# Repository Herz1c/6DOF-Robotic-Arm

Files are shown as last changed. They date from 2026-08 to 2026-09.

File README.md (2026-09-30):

# A robot arm you can print

I am building a six-axis robot arm that you can make at home. Almost every part
of it comes off a 3D printer. What is left over is bearings, stepper
motors and screws, all of it for less than 400$. Alongside the arm I am also
building an AI model for object detection which will run on a Rockchip RK3588.
Camera mount was already added to the model and assembly guides.

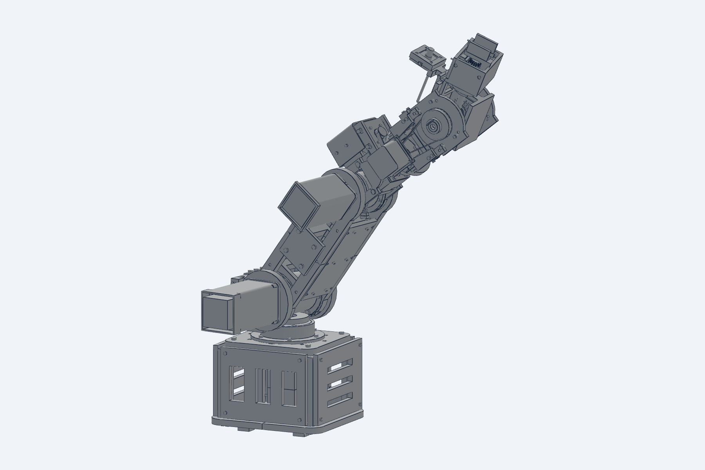
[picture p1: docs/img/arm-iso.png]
The arm


## Where this is right now

Work in progress. What sits in this repository today is the printable parts and
the assembly guide, nothing else.

The arm is fully designed, and I have checked the motion and the fits in CAD.
But I have not built it, and neither has anyone else. So treat these files as
something to print and look at, not as a finished kit that is known to work.

## The assembly guide

The assembly guide has been finally published, both czech and english versions.
The manuals were created not only to show how to put the printed pieces together,
but also to act as a shopping list for all the necessary parts. Soon I am planning 
on publishing links for the items needed (as soon as I finish the build and assure good
quality of the parts)

There is also a 3D version of the guide that runs in the browser:
[herz1c.github.io/6DOF-Robotic-Arm](https://herz1c.github.io/6DOF-Robotic-Arm/).
It puts the arm together one part at a time, all 263 steps, and you can turn the
model around to see where each part goes and which side the screws come from.
It works on a phone and there is nothing to install.

## What is in here

Everything printable, in `print_parts`, split into seven folders that follow the
order you need them:

- base and J1 turret
- J2 shoulder
- J3 elbow and upper arm
- J4 forearm roll
- J5 and J6 differential wrist
- gripper
- forearm lids

Both manuals are in `docs` folder, the browser guide in `docs/guide`

Every part has an STL to print and a STEP next to it if you would rather remesh
it or change something. Each folder has a short readme with the material, layer
height, perimeters, infill, supports and print orientation for each part.

## How the arm works

Six axes, plus a two-finger gripper on the end.

The wrist is the part I am most pleased with. Both wrist motors sit back on the
forearm and never turn with the joint. Two belts drive two input spools, and the
wrist reads the sum of them as pitch and the difference as roll. That means the
tool can spin without ever stopping, because nothing winds up, and it keeps the
weight of two motors off the far end of the arm where you feel it most.

Homing runs on a single pair of wires. The switches are wired in series, so one
break tells the controller a flag arrived, and the axis you were moving tells it
which. The wrist pitch has no switch at all. It finds home by driving gently into
a printed stop.

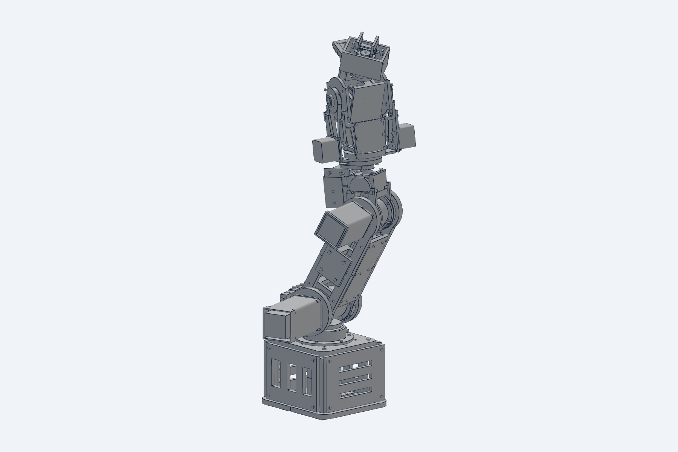
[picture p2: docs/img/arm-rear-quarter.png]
The arm from behind


## A word about material

The readmes name a material for every part and it is worth following. Parts in
the load path or next to a motor are ASA, because stepper bodies get hot enough
that PLA slowly gives way under the permanent squeeze that every bolted joint
lives under.

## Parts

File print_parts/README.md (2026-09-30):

# Printable parts

Every part of the arm that comes off a printer, split into the order you need it. Start with folder 01 and work down - you can begin assembling the base while the rest is still printing.

- `01_base_and_j1` - Base and J1 turret, 27 parts
- `02_j2_shoulder` - J2 shoulder, 9 parts
- `03_j3_elbow` - J3 elbow and upper arm, 19 parts
- `04_j4_forearm` - J4 forearm roll, 26 parts
- `05_j5_j6_wrist` - J5 and J6 differential wrist, 28 parts
- `06_gripper` - Gripper, 9 parts
- `07_forearm_lids` - Forearm lids, 2 parts

Each folder has an STL and a STEP for every part. Print the STL; the STEP is there if you would rather re-mesh it yourself or change something.

The complete Czech and English assembly guides are published in `docs/manual`. Folder order and the three-digit file numbers follow the same build order.

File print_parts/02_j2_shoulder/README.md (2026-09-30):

# J2 shoulder

The shoulder joint and the parts that hold its bearings.

Print these in the order the files are numbered. Settings below are what the part is designed for, not a suggestion - the material choice in particular matters, see the note at the bottom.

1. **HomeSwitchBracket J2** - PETG, 0.15 mm layers, 4 perimeters, 30% infill, supports on overhangs only. Orientation: largest face on the bed, X axis vertical.
2. **J2 FlangedBearingHub** - ASA, 0.20 mm layers, 5 perimeters, 60% infill, no supports. Orientation: bearing bore vertical so it stays round without supports.
3. **HomeFlag J2** - PETG, 0.20 mm layers, 3 perimeters, 30% infill, no supports. Orientation: largest face on the bed, Y axis vertical.
4. **J2 6807 Left OuterRaceSpacer 9mm** - PETG, 0.20 mm layers, 4 perimeters, 30% infill, no supports. Orientation: largest face on the bed, Y axis vertical.
5. **J2 6807 Right OuterRaceSpacer 9mm** - PETG, 0.20 mm layers, 4 perimeters, 30% infill, no supports. Orientation: largest face on the bed, Y axis vertical.
6. **J2 SteppedBearingRetainerAdapter** - ASA, 0.20 mm layers, 5 perimeters, 30% infill, no supports. Orientation: bearing bore vertical so it stays round without supports.
7. **J2 6807 Right ExternalRetainer** - ASA, 0.20 mm layers, 5 perimeters, 30% infill, no supports. Orientation: bearing bore vertical so it stays round without supports.
8. **J2 ActuatorServiceCover M3x4** - PETG, 0.20 mm layers, 4 perimeters, 30% infill, no supports. Orientation: largest face on the bed, X axis vertical.
9. **P217 J2HubDrillJig** - ASA, 0.20 mm layers, 4 perimeters, 60% infill, no supports. Orientation: largest face on the bed, Y axis vertical. This one is a tool, not a part of the arm: the bought J2 hub has no bolt circle, and its eight M5 holes are drilled through this jig.

ASA parts sit in the load path or next to a motor. Stepper bodies run hot enough that PLA creeps there under the permanent load every bolted joint carries, so those parts are not a place to save money. PETG parts are covers, gears, pulleys and brackets.

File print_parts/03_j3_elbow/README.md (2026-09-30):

# J3 elbow and upper arm

The upper arm shell and the elbow joint.

Print these in the order the files are numbered. Settings below are what the part is designed for, not a suggestion - the material choice in particular matters, see the note at the bottom.

1. **UpperArmCheek Left A J2SixBoltHoles** - ASA, 0.20 mm layers, 5 perimeters, 30% infill, supports on overhangs only. Orientation: largest face on the bed, Y axis vertical.
2. **UpperArmCheek Left B 6807InnerShoulder** - ASA, 0.20 mm layers, 5 perimeters, 30% infill, supports on overhangs only. Orientation: largest face on the bed, Y axis vertical.
3. **UpperArmSplice Left** - ASA, 0.20 mm layers, 5 perimeters, 30% infill, no supports. Orientation: largest face on the bed, Y axis vertical.
4. **UpperArmRib A** - ASA, 0.20 mm layers, 5 perimeters, 30% infill, no supports. Orientation: upright, 5 mm brim.
5. **UpperArmRib B** - ASA, 0.20 mm layers, 5 perimeters, 30% infill, no supports. Orientation: upright, 5 mm brim.
6. **UpperArmRibC ElbowSweepWindow** - ASA, 0.20 mm layers, 5 perimeters, 30% infill, no supports. Orientation: upright, 5 mm brim.
7. **UpperArmBottomCover** - PETG, 0.20 mm layers, 4 perimeters, 30% infill, no supports. Orientation: largest face on the bed, Z axis vertical.
8. **HomeSwitchBracket J3** - PETG, 0.15 mm layers, 4 perimeters, 30% infill, supports on overhangs only. Orientation: largest face on the bed, Y axis vertical.
9. **J3 Dual6807JournalHub** - ASA, 0.20 mm layers, 5 perimeters, 60% infill, no supports. Orientation: bearing bore vertical so it stays round without supports.
10. **HomeFlag J3** - PETG, 0.20 mm layers, 3 perimeters, 30% infill, no supports. Orientation: largest face on the bed, Y axis vertical.
11. **ElbowCheek Left** - ASA, 0.20 mm layers, 5 perimeters, 30% infill, supports on overhangs only. Orientation: largest face on the bed, Y axis vertical.
12. **ElbowCheek Right** - ASA, 0.20 mm layers, 5 perimeters, 30% infill, supports on overhangs only. Orientation: largest face on the bed, Y axis vertical.
13. *Not used - there is no file 013. The printed left inner race collar was dropped; the gearbox's own machined register stops the bearing instead.*
14. **P216 J3 LoadCartridge 68mmGearbox** - ASA, 0.15 mm layers, 4 perimeters, 60% infill, supports on overhangs only. Orientation: largest face on the bed, X axis vertical.
15. **UpperArmCheek Right A J2SixBoltHoles** - ASA, 0.20 mm layers, 5 perimeters, 30% infill, supports on overhangs only. Orientation: largest face on the bed, Y axis vertical.
16. **UpperArmCheek Right B 6807InnerShoulder M3Pilots** - ASA, 0.20 mm layers, 5 perimeters, 30% infill, supports on overhangs only. Orientation: largest face on the bed, Y axis vertical.
17. **UpperArmSplice Right** - ASA, 0.20 mm layers, 5 perimeters, 30% infill, no supports. Orientation: largest face on the bed, Y axis vertical.
18. **J3 InnerRaceSetScrewCollar Right** - PETG, 0.20 mm layers, 4 perimeters, 30% infill, no supports. Orientation: bearing bore vertical so it stays round without supports.
19. **J3 Right6807 OuterRaceRetainer Access** - ASA, 0.20 mm layers, 4 perimeters, 30% infill, no supports. Orientation: bearing bore vertical so it stays round without supports.
20. **UpperArmTopCover ElbowSweepWindow** - PETG, 0.20 mm layers, 4 perimeters, 30% infill, no supports. Orientation: largest face on the bed, Z axis vertical.

ASA parts sit in the load path or next to a motor. Stepper bodies run hot enough that PLA creeps there under the permanent load every bolted joint carries, so those parts are not a place to save money. PETG parts are covers, gears, pulleys and brackets.

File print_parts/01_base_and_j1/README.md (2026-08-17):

# Base and J1 turret

The frame that stands on the table and carries everything else, plus the first axis.

Print these in the order the files are numbered. Settings below are what the part is designed for, not a suggestion - the material choice in particular matters, see the note at the bottom.

1. **BaseFloor Left Anchored** - ASA, 0.20 mm layers, 5 perimeters, 30% infill, no supports. Orientation: largest face on the bed, Z axis vertical.
2. **BaseFloor Right Anchored** - ASA, 0.20 mm layers, 5 perimeters, 30% infill, no supports. Orientation: largest face on the bed, Z axis vertical.
3. **BaseFloor UpperSplicePlate** - ASA, 0.20 mm layers, 4 perimeters, 30% infill, no supports. Orientation: largest face on the bed, Z axis vertical.
4. **BaseFloor UpperSplicePlate (1)** - ASA, 0.20 mm layers, 4 perimeters, 30% infill, no supports. Orientation: largest face on the bed, Z axis vertical.
5. **BaseFoot MM** - ASA, 0.20 mm layers, 3 perimeters, 30% infill, no supports. Orientation: largest face on the bed, Z axis vertical.
6. **BaseFoot MP** - ASA, 0.20 mm layers, 3 perimeters, 30% infill, no supports. Orientation: largest face on the bed, Z axis vertical.
7. **BaseFoot PM** - ASA, 0.20 mm layers, 3 perimeters, 30% infill, no supports. Orientation: largest face on the bed, Z axis vertical.
8. **BaseFoot PP** - ASA, 0.20 mm layers, 3 perimeters, 30% infill, no supports. Orientation: largest face on the bed, Z axis vertical.
9. **BaseCornerPost FL** - ASA, 0.20 mm layers, 5 perimeters, 30% infill, no supports. Orientation: upright, 5 mm brim.
10. **BaseCornerPost FR** - ASA, 0.20 mm layers, 5 perimeters, 30% infill, no supports. Orientation: upright, 5 mm brim.
11. **BaseCornerPost RL** - ASA, 0.20 mm layers, 5 perimeters, 30% infill, no supports. Orientation: upright, 5 mm brim.
12. **BaseCornerPost RR** - ASA, 0.20 mm layers, 5 perimeters, 30% infill, no supports. Orientation: upright, 5 mm brim.
13. **BaseFrontPanel** - ASA, 0.20 mm layers, 5 perimeters, 30% infill, no supports. Orientation: largest face on the bed, Y axis vertical.
14. **BaseRearPanel** - ASA, 0.20 mm layers, 5 perimeters, 30% infill, no supports. Orientation: largest face on the bed, Y axis vertical.
15. **BaseLeftPanel** - ASA, 0.20 mm layers, 5 perimeters, 30% infill, no supports. Orientation: largest face on the bed, X axis vertical.
16. **BaseRightPanel** - ASA, 0.20 mm layers, 5 perimeters, 30% infill, no supports. Orientation: largest face on the bed, X axis vertical.
17. **J1 ReducerAndBearingAdapter** - ASA, 0.20 mm layers, 5 perimeters, 30% infill, no supports. Orientation: largest face on the bed, Z axis vertical.
18. **BaseTopPlate J1StackOpening** - ASA, 0.20 mm layers, 5 perimeters, 30% infill, no supports. Orientation: largest face on the bed, Z axis vertical.
19. **J1 DualBearingHousing Flanged** - ASA, 0.20 mm layers, 5 perimeters, 60% infill, supports on overhangs only. Orientation: bearing bore vertical so it stays round without supports.
20. **J1 6807 TopRetainer CSK** - ASA, 0.20 mm layers, 5 perimeters, 30% infill, no supports. Orientation: bearing bore vertical so it stays round without supports.
21. **HomeSwitchBracket J1** - PETG, 0.15 mm layers, 4 perimeters, 30% infill, supports on overhangs only. Orientation: largest face on the bed, Z axis vertical.
22. **P101A J1 JournalCartridge** - ASA, 0.20 mm layers, 5 perimeters, 60% infill, supports on overhangs only. Orientation: largest face on the bed, Z axis vertical.
23. **P101B LowerDeck** - ASA, 0.20 mm layers, 5 perimeters, 30% infill, no supports. Orientation: largest face on the bed, Z axis vertical.
24. **P101E RearBridge** - ASA, 0.20 mm layers, 5 perimeters, 30% infill, no supports. Orientation: largest face on the bed, X axis vertical.
25. **P101C J2Cheek Left** - ASA, 0.20 mm layers, 5 perimeters, 30% infill, supports on overhangs only. Orientation: largest face on the bed, Y axis vertical.
26. **P101D J2Cheek Right** - ASA, 0.20 mm layers, 5 perimeters, 30% infill, supports on overhangs only. Orientation: largest face on the bed, Y axis vertical.
27. **HomeFlag J1** - PETG, 0.20 mm layers, 3 perimeters, 30% infill, no supports. Orientation: largest face on the bed, Z axis vertical.

ASA parts sit in the load path or next to a motor. Stepper bodies run hot enough that PLA creeps there under the permanent load every bolted joint carries, so those parts are not a place to save money. PETG parts are covers, gears, pulleys and brackets.

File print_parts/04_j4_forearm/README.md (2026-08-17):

# J4 forearm roll

Forearm rotation, its belt drive and bearing cartridge.

Print these in the order the files are numbered. Settings below are what the part is designed for, not a suggestion - the material choice in particular matters, see the note at the bottom.

1. **P304A J4 BearingCartridge** - ASA, 0.20 mm layers, 5 perimeters, 60% infill, supports on overhangs only. Orientation: largest face on the bed, X axis vertical.
2. **P304B BottomFoot Rear** - ASA, 0.20 mm layers, 4 perimeters, 30% infill, no supports. Orientation: largest face on the bed, Z axis vertical.
3. **P304C BottomFoot Front** - ASA, 0.20 mm layers, 4 perimeters, 30% infill, no supports. Orientation: largest face on the bed, X axis vertical.
4. **P304D PG19Carrier Rear PosY** - ASA, 0.20 mm layers, 4 perimeters, 30% infill, supports on overhangs only. Orientation: largest face on the bed, Y axis vertical.
5. **P304E PG19Carrier Rear NegY** - ASA, 0.20 mm layers, 4 perimeters, 30% infill, supports on overhangs only. Orientation: largest face on the bed, Y axis vertical.
6. **P304F PG19Carrier Front PosY** - ASA, 0.20 mm layers, 5 perimeters, 30% infill, supports on overhangs only. Orientation: largest face on the bed, X axis vertical.
7. **P304G PG19Carrier Front NegY** - ASA, 0.20 mm layers, 5 perimeters, 30% infill, supports on overhangs only. Orientation: largest face on the bed, X axis vertical.
8. **HomeSwitchBracket J4** - PETG, 0.15 mm layers, 4 perimeters, 30% infill, supports on overhangs only. Orientation: largest face on the bed, X axis vertical.
9. **J4 BearingRetainer Rear FlushCSK** - ASA, 0.20 mm layers, 4 perimeters, 30% infill, no supports. Orientation: bearing bore vertical so it stays round without supports.
10. **J4 BearingRetainer Front** - ASA, 0.20 mm layers, 4 perimeters, 30% infill, no supports. Orientation: bearing bore vertical so it stays round without supports.
11. **36T HTD3M DFlat OutputFlange SingleM5Clamp** - ASA, 0.20 mm layers, 5 perimeters, 60% infill, no supports. Orientation: largest face on the bed, X axis vertical.
12. **P401A J4 OutputFlangeWithTabs** - ASA, 0.20 mm layers, 5 perimeters, 60% infill, no supports. Orientation: largest face on the bed, X axis vertical.
13. **P401B ForearmSideFrame PosY** - ASA, 0.20 mm layers, 5 perimeters, 30% infill, no supports. Orientation: largest face on the bed, Y axis vertical.
14. **P401D RearCrossbar Upper** - ASA, 0.20 mm layers, 4 perimeters, 30% infill, no supports. Orientation: largest face on the bed, X axis vertical.
15. **P401E RearCrossbar Lower** - ASA, 0.20 mm layers, 4 perimeters, 30% infill, no supports. Orientation: largest face on the bed, X axis vertical.
16. **P401F FrontCrossbar Upper** - ASA, 0.20 mm layers, 4 perimeters, 30% infill, no supports. Orientation: largest face on the bed, X axis vertical.
17. **P401G FrontCrossbar Lower** - ASA, 0.20 mm layers, 4 perimeters, 30% infill, no supports. Orientation: largest face on the bed, X axis vertical.
18. **P401C ForearmSideFrame NegY** - ASA, 0.20 mm layers, 5 perimeters, 30% infill, no supports. Orientation: largest face on the bed, Y axis vertical.
19. **HomeFlag J4** - PETG, 0.20 mm layers, 3 perimeters, 30% infill, no supports. Orientation: largest face on the bed, X axis vertical.
20. **J4 PG19 FrontFlangeCarriage** - ASA, 0.20 mm layers, 5 perimeters, 60% infill, no supports. Orientation: largest face on the bed, X axis vertical.
21. **J4 MotorRearSupportClamp** - ASA, 0.20 mm layers, 4 perimeters, 30% infill, no supports. Orientation: largest face on the bed, Z axis vertical.
22. **J4 GearmotorServiceCover Clearanced** - PETG, 0.15 mm layers, 4 perimeters, 30% infill, no supports. Orientation: largest face on the bed, Z axis vertical.
23. **NEMA17 LoadMount A CoverBosses** - ASA, 0.20 mm layers, 4 perimeters, 30% infill, no supports. Orientation: largest face on the bed, Y axis vertical.
24. **NEMA17 OpenBackCover A M3Flange** - PETG, 0.20 mm layers, 4 perimeters, 60% infill, no supports. Orientation: largest face on the bed, Y axis vertical.
25. **NEMA17 LoadMount B CoverBosses** - ASA, 0.20 mm layers, 4 perimeters, 30% infill, no supports. Orientation: largest face on the bed, Y axis vertical.
26. **NEMA17 OpenBackCover B M3Flange** - PETG, 0.20 mm layers, 4 perimeters, 60% infill, no supports. Orientation: largest face on the bed, Y axis vertical.

ASA parts sit in the load path or next to a motor. Stepper bodies run hot enough that PLA creeps there under the permanent load every bolted joint carries, so those parts are not a place to save money. PETG parts are covers, gears, pulleys and brackets.

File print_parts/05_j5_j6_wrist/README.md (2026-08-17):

# J5 and J6 differential wrist

The differential wrist: fork, carrier, spools and tool flange.

Print these in the order the files are numbered. Settings below are what the part is designed for, not a suggestion - the material choice in particular matters, see the note at the bottom.

1. **HollowInputShaft A** - ASA, 0.20 mm layers, 5 perimeters, 30% infill, no supports. Orientation: largest face on the bed, X axis vertical.
2. **60T HTD3M InputPulley A** - PETG, 0.15 mm layers, 4 perimeters, 60% infill, no supports. Orientation: gear axis vertical so the teeth need no supports.
3. **DiffInputClampCollar A** - ASA, 0.20 mm layers, 4 perimeters, 30% infill, no supports. Orientation: bearing bore vertical so it stays round without supports.
4. **HollowInputShaft B** - ASA, 0.20 mm layers, 5 perimeters, 30% infill, no supports. Orientation: largest face on the bed, X axis vertical.
5. **60T HTD3M InputPulley B** - PETG, 0.15 mm layers, 4 perimeters, 60% infill, no supports. Orientation: gear axis vertical so the teeth need no supports.
6. **DiffInputClampCollar B** - ASA, 0.20 mm layers, 4 perimeters, 30% infill, no supports. Orientation: bearing bore vertical so it stays round without supports.
7. **DifferentialFork Left** - ASA, 0.20 mm layers, 5 perimeters, 30% infill, supports on overhangs only. Orientation: largest face on the bed, Y axis vertical.
8. **DifferentialFork Right** - ASA, 0.20 mm layers, 5 perimeters, 30% infill, supports on overhangs only. Orientation: largest face on the bed, Y axis vertical.
9. **HardStop J5 MIN** - ASA, 0.20 mm layers, 3 perimeters, 30% infill, no supports. Orientation: largest face on the bed, Y axis vertical.
10. **HardStop J5 MAX** - ASA, 0.20 mm layers, 3 perimeters, 30% infill, no supports. Orientation: largest face on the bed, Y axis vertical.
11. **DiffInputBearingRetainer A** - ASA, 0.20 mm layers, 4 perimeters, 30% infill, no supports. Orientation: bearing bore vertical so it stays round without supports.
12. **DiffInputBearingRetainer B** - ASA, 0.20 mm layers, 4 perimeters, 30% infill, no supports. Orientation: bearing bore vertical so it stays round without supports.
13. **J5 PitchBearingHousing A** - ASA, 0.20 mm layers, 4 perimeters, 60% infill, supports on overhangs only. Orientation: bearing bore vertical so it stays round without supports.
14. **J5 PitchBearingHousing B** - ASA, 0.20 mm layers, 4 perimeters, 60% infill, supports on overhangs only. Orientation: bearing bore vertical so it stays round without supports.
15. **DifferentialCarrier SeparatedBearingStack** - ASA, 0.20 mm layers, 5 perimeters, 30% infill, supports on overhangs only. Orientation: largest face on the bed, Z axis vertical.
16. **HardStopStriker J5** - ASA, 0.20 mm layers, 3 perimeters, 30% infill, no supports. Orientation: largest face on the bed, Z axis vertical.
17. **HomeSwitchBracket J6** - PETG, 0.15 mm layers, 4 perimeters, 30% infill, supports on overhangs only. Orientation: largest face on the bed, X axis vertical.
18. **J6 HollowD12 DFlatShaft 8mmBore** - ASA, 0.20 mm layers, 5 perimeters, 30% infill, no supports. Orientation: largest face on the bed, Y axis vertical.
19. **HomeFlag J6** - PETG, 0.20 mm layers, 3 perimeters, 30% infill, no supports. Orientation: largest face on the bed, X axis vertical.
20. **24T m2 StraightBevelJ6 DFlat** - PETG, 0.15 mm layers, 4 perimeters, 60% infill, no supports. Orientation: gear axis vertical so the teeth need no supports.
21. **J6 DFlatToolHub R28** - ASA, 0.20 mm layers, 4 perimeters, 60% infill, no supports. Orientation: bearing bore vertical so it stays round without supports.
22. **ISO50 ToolFlange Counterbored** - ASA, 0.20 mm layers, 5 perimeters, 60% infill, no supports. Orientation: largest face on the bed, X axis vertical.
23. **J6 RearBearingRetainer CSK** - ASA, 0.20 mm layers, 4 perimeters, 30% infill, no supports. Orientation: bearing bore vertical so it stays round without supports.
24. **CapsuleSlipRingClamp M125** - ASA, 0.20 mm layers, 4 perimeters, 30% infill, no supports. Orientation: largest face on the bed, X axis vertical.
25. **J6 FrontBearingRetainer CSK** - ASA, 0.20 mm layers, 4 perimeters, 30% infill, no supports. Orientation: bearing bore vertical so it stays round without supports.
26. **OV5693 CameraMount Upper** - ASA, 0.20 mm layers, 5 perimeters, 40% infill, no supports. Orientation: plochou svěrky na podložku; M2 drážky svisle.
27. **OV5693 CameraClamp Lower** - ASA, 0.20 mm layers, 5 perimeters, 40% infill, no supports. Orientation: plochou čelisti na podložku; otevřený U výřez nahoru.
28. **OV5693 CameraGuard** - ASA, 0.20 mm layers, 4 perimeters, 40% infill, no supports. Orientation: zadní plochou na podložku; otvor objektivu bez podpěr.

ASA parts sit in the load path or next to a motor. Stepper bodies run hot enough that PLA creeps there under the permanent load every bolted joint carries, so those parts are not a place to save money. PETG parts are covers, gears, pulleys and brackets.

## Camera module

Final camera: [RGB USB UVC OV5693 5MP on AliExpress](https://pl.aliexpress.com/item/1005005603460226.html?gatewayAdapt=glo2pol). Use the 32–38 mm PCB clamp range and focus the M12 lens after the camera is bolted to the fixed J5 carrier.

Camera hardware: 2x M3x20 clamp screw, 4x M2x8 PCB screw, four 3–4 mm spacers and 2x M3x8 guard screw. Route USB rearward with strain relief and a J5 service loop; never through J6.

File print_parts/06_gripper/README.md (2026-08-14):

# Gripper

Two-finger gripper: palm, pinion, carriages and jaws.

Print these in the order the files are numbered. Settings below are what the part is designed for, not a suggestion - the material choice in particular matters, see the note at the bottom.

1. **GripperPalm** - ASA, 0.20 mm layers, 5 perimeters, 30% infill, supports on overhangs only. Orientation: largest face on the bed, X axis vertical.
2. **GripperPalm (1)** - ASA, 0.20 mm layers, 3 perimeters, 30% infill, supports on overhangs only. Orientation: largest face on the bed, Y axis vertical. Not another palm - this is one of the two small stops that limit how far the jaws travel.
3. **GripperPalm (2)** - ASA, 0.20 mm layers, 3 perimeters, 30% infill, supports on overhangs only. Orientation: largest face on the bed, Y axis vertical. The second jaw travel stop.
4. **GripperPinion 16T m1p5** - PETG, 0.15 mm layers, 4 perimeters, 60% infill, no supports. Orientation: gear axis vertical so the teeth need no supports.
5. **JawCarriage A** - ASA, 0.20 mm layers, 4 perimeters, 60% infill, no supports. Orientation: largest face on the bed, X axis vertical.
6. **JawCarriage B** - ASA, 0.20 mm layers, 4 perimeters, 60% infill, no supports. Orientation: largest face on the bed, X axis vertical.
7. **JawTip A** - PETG, 0.20 mm layers, 4 perimeters, 30% infill, no supports. Orientation: largest face on the bed, Y axis vertical.
8. **JawTip B** - PETG, 0.20 mm layers, 4 perimeters, 30% infill, no supports. Orientation: largest face on the bed, Y axis vertical.
9. **GripperServiceCover** - PETG, 0.20 mm layers, 4 perimeters, 30% infill, no supports. Orientation: largest face on the bed, Z axis vertical.

ASA parts sit in the load path or next to a motor. Stepper bodies run hot enough that PLA creeps there under the permanent load every bolted joint carries, so those parts are not a place to save money. PETG parts are covers, gears, pulleys and brackets.

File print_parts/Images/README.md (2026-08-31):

# Printable-part images

Exactly one released printable STEP part is shown in each PNG. Images
are orthographic isometric CAD snapshots; no motors, hardware, assembly
context, or second printable body is included.

The PNG basename matches the STEP/STL basename in the section folders.

| section | part | image |
|---|---|---|
| 01_base_and_j1 | `001_BaseFloor_Left_Anchored` | [001_BaseFloor_Left_Anchored.png](001_BaseFloor_Left_Anchored.png) |
| 01_base_and_j1 | `002_BaseFloor_Right_Anchored` | [002_BaseFloor_Right_Anchored.png](002_BaseFloor_Right_Anchored.png) |
| 01_base_and_j1 | `003_BaseFloor_UpperSplicePlate` | [003_BaseFloor_UpperSplicePlate.png](003_BaseFloor_UpperSplicePlate.png) |
| 01_base_and_j1 | `004_BaseFloor_UpperSplicePlate_1` | [004_BaseFloor_UpperSplicePlate_1.png](004_BaseFloor_UpperSplicePlate_1.png) |
| 01_base_and_j1 | `005_BaseFoot_MM` | [005_BaseFoot_MM.png](005_BaseFoot_MM.png) |
| 01_base_and_j1 | `006_BaseFoot_MP` | [006_BaseFoot_MP.png](006_BaseFoot_MP.png) |
| 01_base_and_j1 | `007_BaseFoot_PM` | [007_BaseFoot_PM.png](007_BaseFoot_PM.png) |
| 01_base_and_j1 | `008_BaseFoot_PP` | [008_BaseFoot_PP.png](008_BaseFoot_PP.png) |
| 01_base_and_j1 | `009_BaseCornerPost_FL` | [009_BaseCornerPost_FL.png](009_BaseCornerPost_FL.png) |
| 01_base_and_j1 | `010_BaseCornerPost_FR` | [010_BaseCornerPost_FR.png](010_BaseCornerPost_FR.png) |
| 01_base_and_j1 | `011_BaseCornerPost_RL` | [011_BaseCornerPost_RL.png](011_BaseCornerPost_RL.png) |
| 01_base_and_j1 | `012_BaseCornerPost_RR` | [012_BaseCornerPost_RR.png](012_BaseCornerPost_RR.png) |
| 01_base_and_j1 | `013_BaseFrontPanel` | [013_BaseFrontPanel.png](013_BaseFrontPanel.png) |
| 01_base_and_j1 | `014_BaseRearPanel` | [014_BaseRearPanel.png](014_BaseRearPanel.png) |
| 01_base_and_j1 | `015_BaseLeftPanel` | [015_BaseLeftPanel.png](015_BaseLeftPanel.png) |
| 01_base_and_j1 | `016_BaseRightPanel` | [016_BaseRightPanel.png](016_BaseRightPanel.png) |
| 01_base_and_j1 | `017_J1_ReducerAndBearingAdapter` | [017_J1_ReducerAndBearingAdapter.png](017_J1_ReducerAndBearingAdapter.png) |
| 01_base_and_j1 | `018_BaseTopPlate_J1StackOpening` | [018_BaseTopPlate_J1StackOpening.png](018_BaseTopPlate_J1StackOpening.png) |
| 01_base_and_j1 | `019_J1_DualBearingHousing_Flanged` | [019_J1_DualBearingHousing_Flanged.png](019_J1_DualBearingHousing_Flanged.png) |
| 01_base_and_j1 | `020_J1_6807_TopRetainer_CSK` | [020_J1_6807_TopRetainer_CSK.png](020_J1_6807_TopRetainer_CSK.png) |
| 01_base_and_j1 | `021_HomeSwitchBracket_J1` | [021_HomeSwitchBracket_J1.png](021_HomeSwitchBracket_J1.png) |
| 01_base_and_j1 | `022_P101A_J1_JournalCartridge` | [022_P101A_J1_JournalCartridge.png](022_P101A_J1_JournalCartridge.png) |
| 01_base_and_j1 | `023_P101B_LowerDeck` | [023_P101B_LowerDeck.png](023_P101B_LowerDeck.png) |
| 01_base_and_j1 | `024_P101E_RearBridge` | [024_P101E_RearBridge.png](024_P101E_RearBridge.png) |
| 01_base_and_j1 | `025_P101C_J2Cheek_Left` | [025_P101C_J2Cheek_Left.png](025_P101C_J2Cheek_Left.png) |
| 01_base_and_j1 | `026_P101D_J2Cheek_Right` | [026_P101D_J2Cheek_Right.png](026_P101D_J2Cheek_Right.png) |
| 01_base_and_j1 | `027_HomeFlag_J1` | [027_HomeFlag_J1.png](027_HomeFlag_J1.png) |
| 02_j2_shoulder | `001_HomeSwitchBracket_J2` | [001_HomeSwitchBracket_J2.png](001_HomeSwitchBracket_J2.png) |
| 02_j2_shoulder | `002_J2_FlangedBearingHub` | [002_J2_FlangedBearingHub.png](002_J2_FlangedBearingHub.png) |
| 02_j2_shoulder | `003_HomeFlag_J2` | [003_HomeFlag_J2.png](003_HomeFlag_J2.png) |
| 02_j2_shoulder | `004_J2_6807_Left_OuterRaceSpacer_9mm` | [004_J2_6807_Left_OuterRaceSpacer_9mm.png](004_J2_6807_Left_OuterRaceSpacer_9mm.png) |
| 02_j2_shoulder | `005_J2_6807_Right_OuterRaceSpacer_9mm` | [005_J2_6807_Right_OuterRaceSpacer_9mm.png](005_J2_6807_Right_OuterRaceSpacer_9mm.png) |
| 02_j2_shoulder | `006_J2_SteppedBearingRetainerAdapter` | [006_J2_SteppedBearingRetainerAdapter.png](006_J2_SteppedBearingRetainerAdapter.png) |
| 02_j2_shoulder | `007_J2_6807_Right_ExternalRetainer` | [007_J2_6807_Right_ExternalRetainer.png](007_J2_6807_Right_ExternalRetainer.png) |
| 02_j2_shoulder | `008_J2_ActuatorServiceCover_M3x4` | [008_J2_ActuatorServiceCover_M3x4.png](008_J2_ActuatorServiceCover_M3x4.png) |
| 02_j2_shoulder | `009_P217_J2HubDrillJig` | [009_P217_J2HubDrillJig.png](009_P217_J2HubDrillJig.png) |
| 03_j3_elbow | `001_UpperArmCheek_Left_A_J2SixBoltHoles` | [001_UpperArmCheek_Left_A_J2SixBoltHoles.png](001_UpperArmCheek_Left_A_J2SixBoltHoles.png) |
| 03_j3_elbow | `002_UpperArmCheek_Left_B_6807InnerShoulder` | [002_UpperArmCheek_Left_B_6807InnerShoulder.png](002_UpperArmCheek_Left_B_6807InnerShoulder.png) |
| 03_j3_elbow | `003_UpperArmSplice_Left` | [003_UpperArmSplice_Left.png](003_UpperArmSplice_Left.png) |
| 03_j3_elbow | `004_UpperArmRib_A` | [004_UpperArmRib_A.png](004_UpperArmRib_A.png) |
| 03_j3_elbow | `005_UpperArmRib_B` | [005_UpperArmRib_B.png](005_UpperArmRib_B.png) |
| 03_j3_elbow | `006_UpperArmRibC_ElbowSweepWindow` | [006_UpperArmRibC_ElbowSweepWindow.png](006_UpperArmRibC_ElbowSweepWindow.png) |
| 03_j3_elbow | `007_UpperArmBottomCover` | [007_UpperArmBottomCover.png](007_UpperArmBottomCover.png) |
| 03_j3_elbow | `008_HomeSwitchBracket_J3` | [008_HomeSwitchBracket_J3.png](008_HomeSwitchBracket_J3.png) |
| 03_j3_elbow | `009_J3_Dual6807JournalHub` | [009_J3_Dual6807JournalHub.png](009_J3_Dual6807JournalHub.png) |
| 03_j3_elbow | `010_HomeFlag_J3` | [010_HomeFlag_J3.png](010_HomeFlag_J3.png) |
| 03_j3_elbow | `011_ElbowCheek_Left` | [011_ElbowCheek_Left.png](011_ElbowCheek_Left.png) |
| 03_j3_elbow | `012_ElbowCheek_Right` | [012_ElbowCheek_Right.png](012_ElbowCheek_Right.png) |
| 03_j3_elbow | `014_P216_J3_LoadCartridge_68mmGearbox` | [014_P216_J3_LoadCartridge_68mmGearbox.png](014_P216_J3_LoadCartridge_68mmGearbox.png) |
| 03_j3_elbow | `015_UpperArmCheek_Right_A_J2SixBoltHoles` | [015_UpperArmCheek_Right_A_J2SixBoltHoles.png](015_UpperArmCheek_Right_A_J2SixBoltHoles.png) |
| 03_j3_elbow | `016_UpperArmCheek_Right_B_6807InnerShoulder_M3Pilots` | [016_UpperArmCheek_Right_B_6807InnerShoulder_M3Pilots.png](016_UpperArmCheek_Right_B_6807InnerShoulder_M3Pilots.png) |
| 03_j3_elbow | `017_UpperArmSplice_Right` | [017_UpperArmSplice_Right.png](017_UpperArmSplice_Right.png) |
| 03_j3_elbow | `018_J3_InnerRaceSetScrewCollar_Right` | [018_J3_InnerRaceSetScrewCollar_Right.png](018_J3_InnerRaceSetScrewCollar_Right.png) |
| 03_j3_elbow | `019_J3_Right6807_OuterRaceRetainer_Access` | [019_J3_Right6807_OuterRaceRetainer_Access.png](019_J3_Right6807_OuterRaceRetainer_Access.png) |
| 03_j3_elbow | `020_UpperArmTopCover_ElbowSweepWindow` | [020_UpperArmTopCover_ElbowSweepWindow.png](020_UpperArmTopCover_ElbowSweepWindow.png) |
| 04_j4_forearm | `001_P304A_J4_BearingCartridge` | [001_P304A_J4_BearingCartridge.png](001_P304A_J4_BearingCartridge.png) |
| 04_j4_forearm | `002_P304B_BottomFoot_Rear` | [002_P304B_BottomFoot_Rear.png](002_P304B_BottomFoot_Rear.png) |
| 04_j4_forearm | `003_P304C_BottomFoot_Front` | [003_P304C_BottomFoot_Front.png](003_P304C_BottomFoot_Front.png) |
| 04_j4_forearm | `004_P304D_PG19Carrier_Rear_PosY` | [004_P304D_PG19Carrier_Rear_PosY.png](004_P304D_PG19Carrier_Rear_PosY.png) |
| 04_j4_forearm | `005_P304E_PG19Carrier_Rear_NegY` | [005_P304E_PG19Carrier_Rear_NegY.png](005_P304E_PG19Carrier_Rear_NegY.png) |
| 04_j4_forearm | `006_P304F_PG19Carrier_Front_PosY` | [006_P304F_PG19Carrier_Front_PosY.png](006_P304F_PG19Carrier_Front_PosY.png) |
| 04_j4_forearm | `007_P304G_PG19Carrier_Front_NegY` | [007_P304G_PG19Carrier_Front_NegY.png](007_P304G_PG19Carrier_Front_NegY.png) |
| 04_j4_forearm | `008_HomeSwitchBracket_J4` | [008_HomeSwitchBracket_J4.png](008_HomeSwitchBracket_J4.png) |
| 04_j4_forearm | `009_J4_BearingRetainer_Rear_FlushCSK` | [009_J4_BearingRetainer_Rear_FlushCSK.png](009_J4_BearingRetainer_Rear_FlushCSK.png) |
| 04_j4_forearm | `010_J4_BearingRetainer_Front` | [010_J4_BearingRetainer_Front.png](010_J4_BearingRetainer_Front.png) |
| 04_j4_forearm | `011_36T_HTD3M_DFlat_OutputFlange_SingleM5Clamp` | [011_36T_HTD3M_DFlat_OutputFlange_SingleM5Clamp.png](011_36T_HTD3M_DFlat_OutputFlange_SingleM5Clamp.png) |
| 04_j4_forearm | `012_P401A_J4_OutputFlangeWithTabs` | [012_P401A_J4_OutputFlangeWithTabs.png](012_P401A_J4_OutputFlangeWithTabs.png) |
| 04_j4_forearm | `013_P401B_ForearmSideFrame_PosY` | [013_P401B_ForearmSideFrame_PosY.png](013_P401B_ForearmSideFrame_PosY.png) |
| 04_j4_forearm | `014_P401D_RearCrossbar_Upper` | [014_P401D_RearCrossbar_Upper.png](014_P401D_RearCrossbar_Upper.png) |
| 04_j4_forearm | `015_P401E_RearCrossbar_Lower` | [015_P401E_RearCrossbar_Lower.png](015_P401E_RearCrossbar_Lower.png) |
| 04_j4_forearm | `016_P401F_FrontCrossbar_Upper` | [016_P401F_FrontCrossbar_Upper.png](016_P401F_FrontCrossbar_Upper.png) |
| 04_j4_forearm | `017_P401G_FrontCrossbar_Lower` | [017_P401G_FrontCrossbar_Lower.png](017_P401G_FrontCrossbar_Lower.png) |
| 04_j4_forearm | `018_P401C_ForearmSideFrame_NegY` | [018_P401C_ForearmSideFrame_NegY.png](018_P401C_ForearmSideFrame_NegY.png) |
| 04_j4_forearm | `019_HomeFlag_J4` | [019_HomeFlag_J4.png](019_HomeFlag_J4.png) |
| 04_j4_forearm | `020_J4_PG19_FrontFlangeCarriage` | [020_J4_PG19_FrontFlangeCarriage.png](020_J4_PG19_FrontFlangeCarriage.png) |
| 04_j4_forearm | `021_J4_MotorRearSupportClamp` | [021_J4_MotorRearSupportClamp.png](021_J4_MotorRearSupportClamp.png) |
| 04_j4_forearm | `022_J4_GearmotorServiceCover_Clearanced` | [022_J4_GearmotorServiceCover_Clearanced.png](022_J4_GearmotorServiceCover_Clearanced.png) |
| 04_j4_forearm | `023_NEMA17_LoadMount_A_CoverBosses` | [023_NEMA17_LoadMount_A_CoverBosses.png](023_NEMA17_LoadMount_A_CoverBosses.png) |
| 04_j4_forearm | `024_NEMA17_OpenBackCover_A_M3Flange` | [024_NEMA17_OpenBackCover_A_M3Flange.png](024_NEMA17_OpenBackCover_A_M3Flange.png) |
| 04_j4_forearm | `025_NEMA17_LoadMount_B_CoverBosses` | [025_NEMA17_LoadMount_B_CoverBosses.png](025_NEMA17_LoadMount_B_CoverBosses.png) |
| 04_j4_forearm | `026_NEMA17_OpenBackCover_B_M3Flange` | [026_NEMA17_OpenBackCover_B_M3Flange.png](026_NEMA17_OpenBackCover_B_M3Flange.png) |
| 05_j5_j6_wrist | `001_HollowInputShaft_A` | [001_HollowInputShaft_A.png](001_HollowInputShaft_A.png) |
| 05_j5_j6_wrist | `002_60T_HTD3M_InputPulley_A` | [002_60T_HTD3M_InputPulley_A.png](002_60T_HTD3M_InputPulley_A.png) |
| 05_j5_j6_wrist | `003_DiffInputClampCollar_A` | [003_DiffInputClampCollar_A.png](003_DiffInputClampCollar_A.png) |
| 05_j5_j6_wrist | `004_HollowInputShaft_B` | [004_HollowInputShaft_B.png](004_HollowInputShaft_B.png) |
| 05_j5_j6_wrist | `005_60T_HTD3M_InputPulley_B` | [005_60T_HTD3M_InputPulley_B.png](005_60T_HTD3M_InputPulley_B.png) |
| 05_j5_j6_wrist | `006_DiffInputClampCollar_B` | [006_DiffInputClampCollar_B.png](006_DiffInputClampCollar_B.png) |
| 05_j5_j6_wrist | `007_DifferentialFork_Left` | [007_DifferentialFork_Left.png](007_DifferentialFork_Left.png) |
| 05_j5_j6_wrist | `008_DifferentialFork_Right` | [008_DifferentialFork_Right.png](008_DifferentialFork_Right.png) |
| 05_j5_j6_wrist | `009_HardStop_J5_MIN` | [009_HardStop_J5_MIN.png](009_HardStop_J5_MIN.png) |
| 05_j5_j6_wrist | `010_HardStop_J5_MAX` | [010_HardStop_J5_MAX.png](010_HardStop_J5_MAX.png) |
| 05_j5_j6_wrist | `011_DiffInputBearingRetainer_A` | [011_DiffInputBearingRetainer_A.png](011_DiffInputBearingRetainer_A.png) |
| 05_j5_j6_wrist | `012_DiffInputBearingRetainer_B` | [012_DiffInputBearingRetainer_B.png](012_DiffInputBearingRetainer_B.png) |
| 05_j5_j6_wrist | `013_J5_PitchBearingHousing_A` | [013_J5_PitchBearingHousing_A.png](013_J5_PitchBearingHousing_A.png) |
| 05_j5_j6_wrist | `014_J5_PitchBearingHousing_B` | [014_J5_PitchBearingHousing_B.png](014_J5_PitchBearingHousing_B.png) |
| 05_j5_j6_wrist | `015_DifferentialCarrier_SeparatedBearingStack` | [015_DifferentialCarrier_SeparatedBearingStack.png](015_DifferentialCarrier_SeparatedBearingStack.png) |
| 05_j5_j6_wrist | `016_HardStopStriker_J5` | [016_HardStopStriker_J5.png](016_HardStopStriker_J5.png) |
| 05_j5_j6_wrist | `017_HomeSwitchBracket_J6` | [017_HomeSwitchBracket_J6.png](017_HomeSwitchBracket_J6.png) |
| 05_j5_j6_wrist | `018_J6_HollowD12_DFlatShaft_8mmBore` | [018_J6_HollowD12_DFlatShaft_8mmBore.png](018_J6_HollowD12_DFlatShaft_8mmBore.png) |
| 05_j5_j6_wrist | `019_HomeFlag_J6` | [019_HomeFlag_J6.png](019_HomeFlag_J6.png) |
| 05_j5_j6_wrist | `020_24T_m2_StraightBevelJ6_DFlat` | [020_24T_m2_StraightBevelJ6_DFlat.png](020_24T_m2_StraightBevelJ6_DFlat.png) |
| 05_j5_j6_wrist | `021_J6_DFlatToolHub_R28` | [021_J6_DFlatToolHub_R28.png](021_J6_DFlatToolHub_R28.png) |
| 05_j5_j6_wrist | `022_ISO50_ToolFlange_Counterbored` | [022_ISO50_ToolFlange_Counterbored.png](022_ISO50_ToolFlange_Counterbored.png) |
| 05_j5_j6_wrist | `023_J6_RearBearingRetainer_CSK` | [023_J6_RearBearingRetainer_CSK.png](023_J6_RearBearingRetainer_CSK.png) |
| 05_j5_j6_wrist | `024_CapsuleSlipRingClamp_M125` | [024_CapsuleSlipRingClamp_M125.png](024_CapsuleSlipRingClamp_M125.png) |
| 05_j5_j6_wrist | `025_J6_FrontBearingRetainer_CSK` | [025_J6_FrontBearingRetainer_CSK.png](025_J6_FrontBearingRetainer_CSK.png) |
| 05_j5_j6_wrist | `026_OV5693_CameraMount_Upper` | [026_OV5693_CameraMount_Upper.png](026_OV5693_CameraMount_Upper.png) |
| 05_j5_j6_wrist | `027_OV5693_CameraClamp_Lower` | [027_OV5693_CameraClamp_Lower.png](027_OV5693_CameraClamp_Lower.png) |
| 05_j5_j6_wrist | `028_OV5693_CameraGuard` | [028_OV5693_CameraGuard.png](028_OV5693_CameraGuard.png) |
| 06_gripper | `001_GripperPalm` | [001_GripperPalm.png](001_GripperPalm.png) |
| 06_gripper | `002_GripperPalm_1` | [002_GripperPalm_1.png](002_GripperPalm_1.png) |
| 06_gripper | `003_GripperPalm_2` | [003_GripperPalm_2.png](003_GripperPalm_2.png) |
| 06_gripper | `004_GripperPinion_16T_m1p5` | [004_GripperPinion_16T_m1p5.png](004_GripperPinion_16T_m1p5.png) |
| 06_gripper | `005_JawCarriage_A` | [005_JawCarriage_A.png](005_JawCarriage_A.png) |
| 06_gripper | `006_JawCarriage_B` | [006_JawCarriage_B.png](006_JawCarriage_B.png) |
| 06_gripper | `007_JawTip_A` | [007_JawTip_A.png](007_JawTip_A.png) |
| 06_gripper | `008_JawTip_B` | [008_JawTip_B.png](008_JawTip_B.png) |
| 06_gripper | `009_GripperServiceCover` | [009_GripperServiceCover.png](009_GripperServiceCover.png) |
| 07_forearm_lids | `001_ForearmDorsalLid_Aligned` | [001_ForearmDorsalLid_Aligned.png](001_ForearmDorsalLid_Aligned.png) |
| 07_forearm_lids | `002_ForearmVentralLid_Aligned` | [002_ForearmVentralLid_Aligned.png](002_ForearmVentralLid_Aligned.png) |

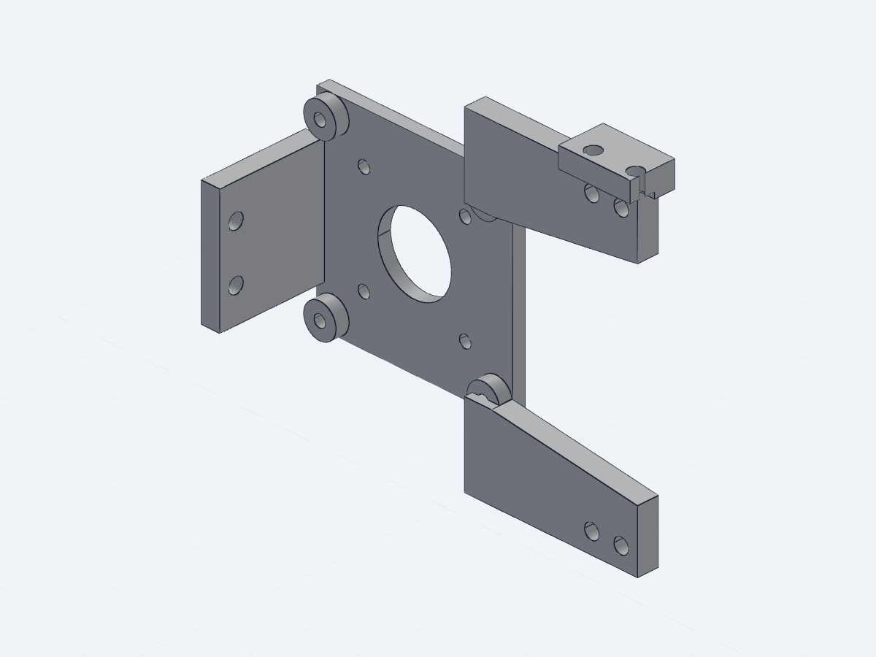
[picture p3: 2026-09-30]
print_parts/Images/025_NEMA17_LoadMount_B_CoverBosses.png

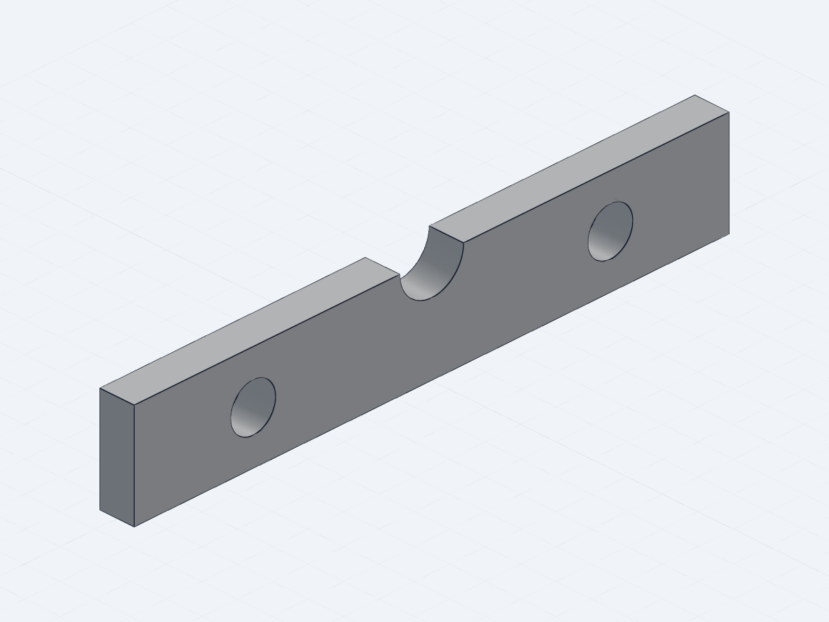
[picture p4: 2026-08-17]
print_parts/Images/003_P304C_BottomFoot_Front.png

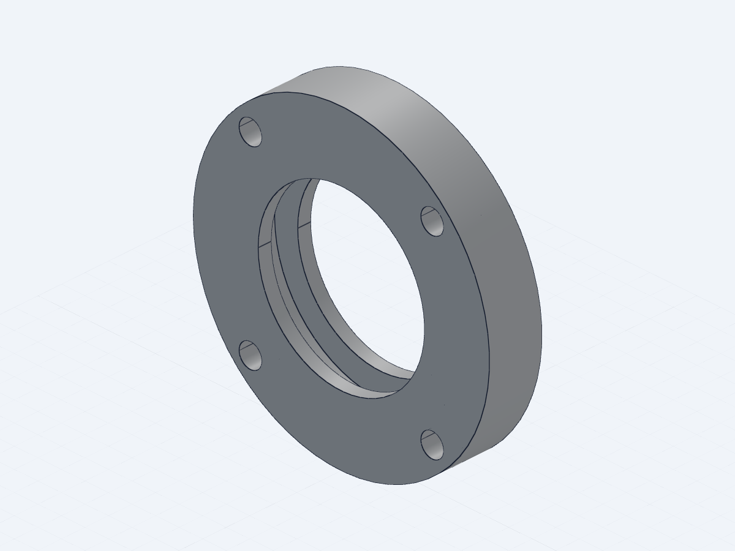
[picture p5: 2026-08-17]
print_parts/Images/013_J5_PitchBearingHousing_A.png

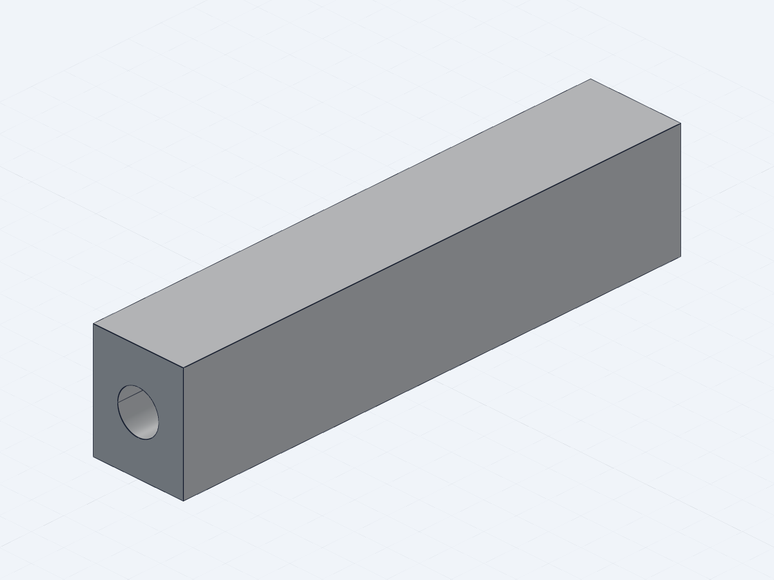
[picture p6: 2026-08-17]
print_parts/Images/016_P401F_FrontCrossbar_Upper.png

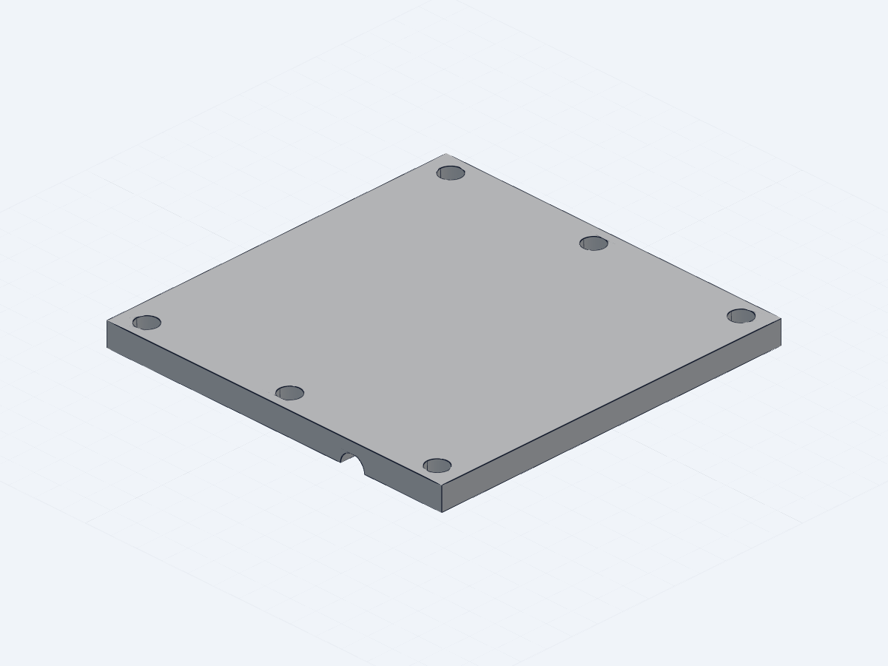
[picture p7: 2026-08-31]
print_parts/Images/001_ForearmDorsalLid_Aligned.png

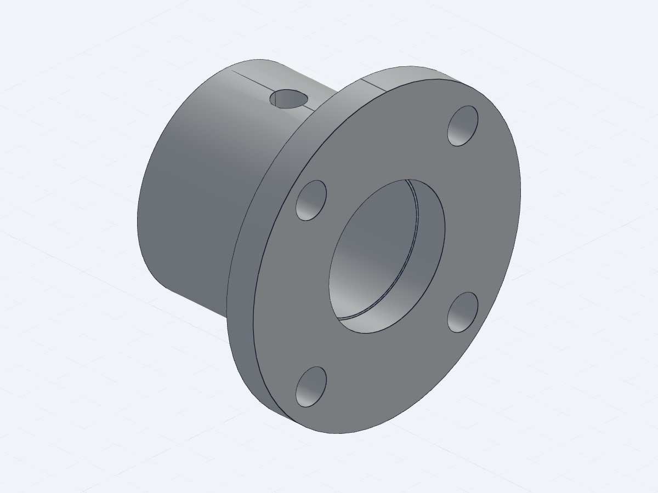
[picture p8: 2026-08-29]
print_parts/Images/024_CapsuleSlipRingClamp_M125.png

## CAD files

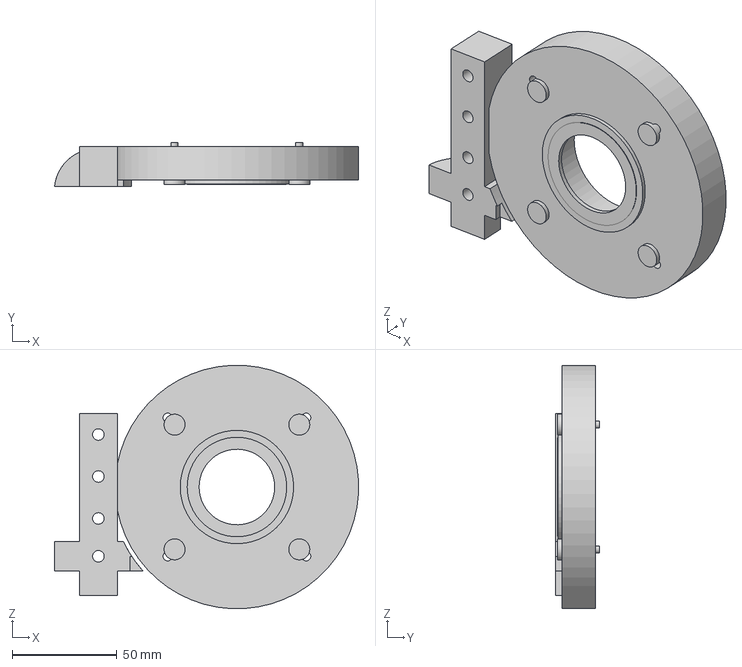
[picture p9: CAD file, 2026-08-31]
print_parts/01_base_and_j1/026_P101D_J2Cheek_Right.step
144.8 x 21.0 x 115.9 mm

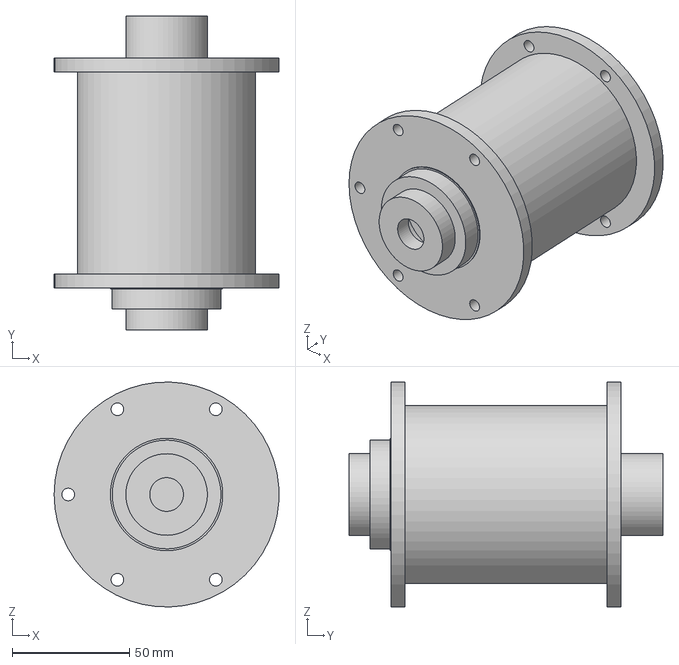
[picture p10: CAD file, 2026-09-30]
print_parts/02_j2_shoulder/002_J2_FlangedBearingHub.step
95.9 x 134.0 x 96.0 mm

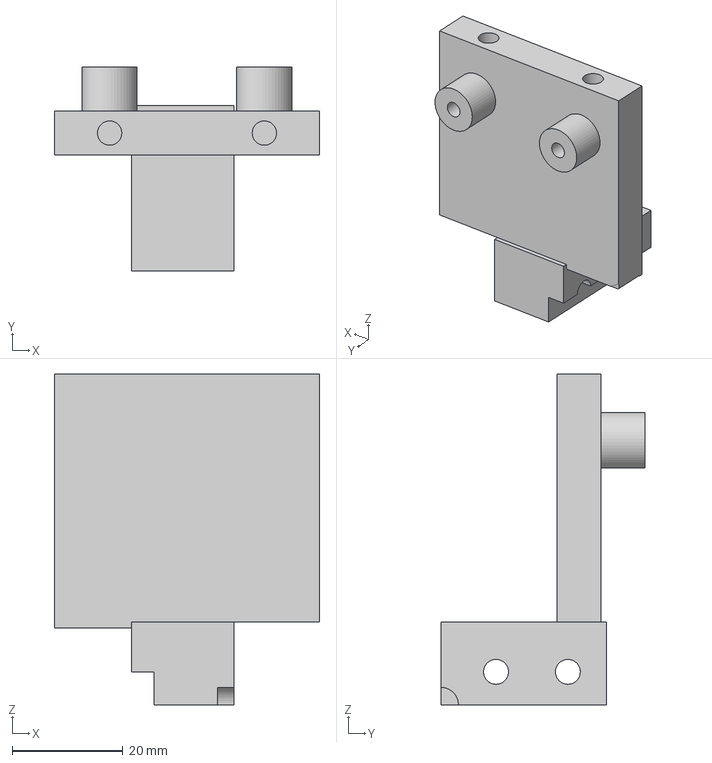
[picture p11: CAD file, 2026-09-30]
print_parts/04_j4_forearm/004_P304D_PG19Carrier_Rear_PosY.step
48.0 x 37.0 x 59.9 mm

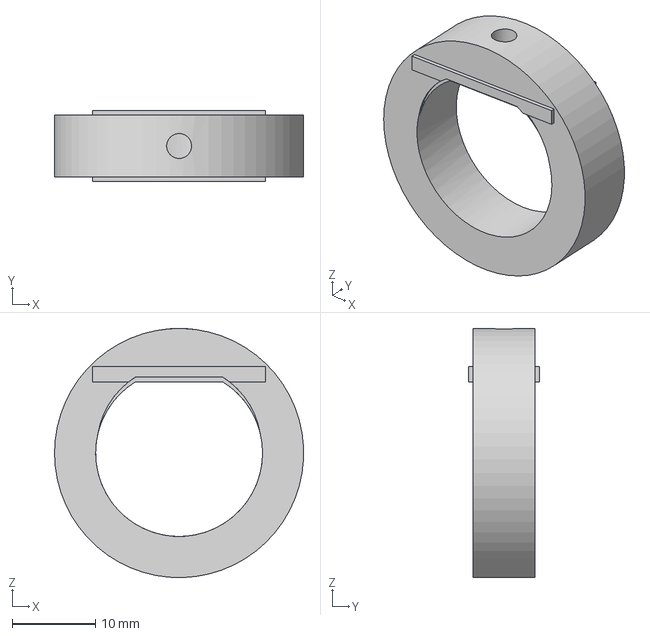
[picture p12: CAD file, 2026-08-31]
print_parts/05_j5_j6_wrist/006_DiffInputClampCollar_B.step
30.0 x 8.50 x 30.0 mm

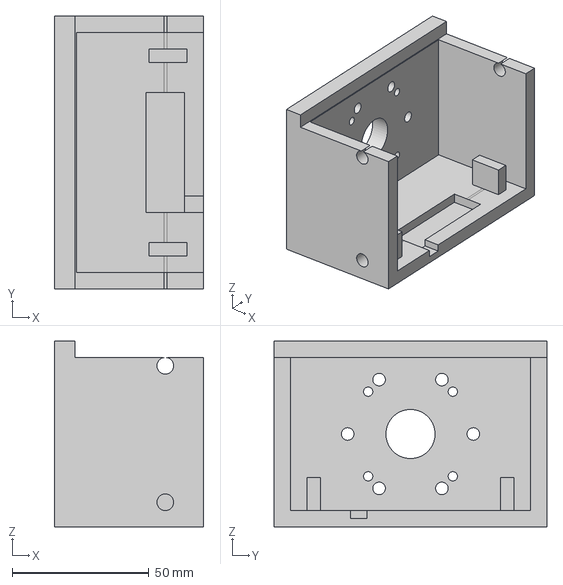
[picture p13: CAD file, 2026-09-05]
print_parts/06_gripper/001_GripperPalm.step
54.6 x 100.0 x 68.0 mm

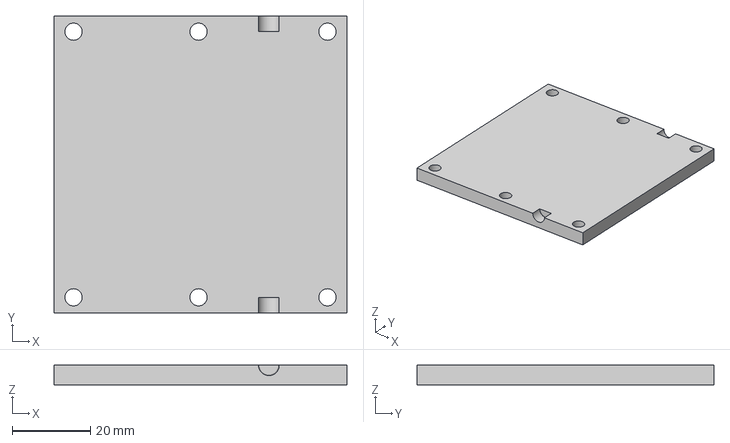
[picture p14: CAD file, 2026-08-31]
print_parts/07_forearm_lids/002_ForearmVentralLid_Aligned.step
75.0 x 76.0 x 5.00 mm

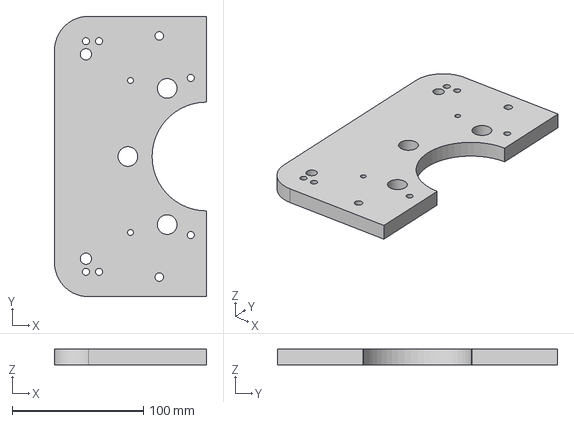
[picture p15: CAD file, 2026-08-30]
print_parts/01_base_and_j1/001_BaseFloor_Left_Anchored.step
116.0 x 214.0 x 12.0 mm

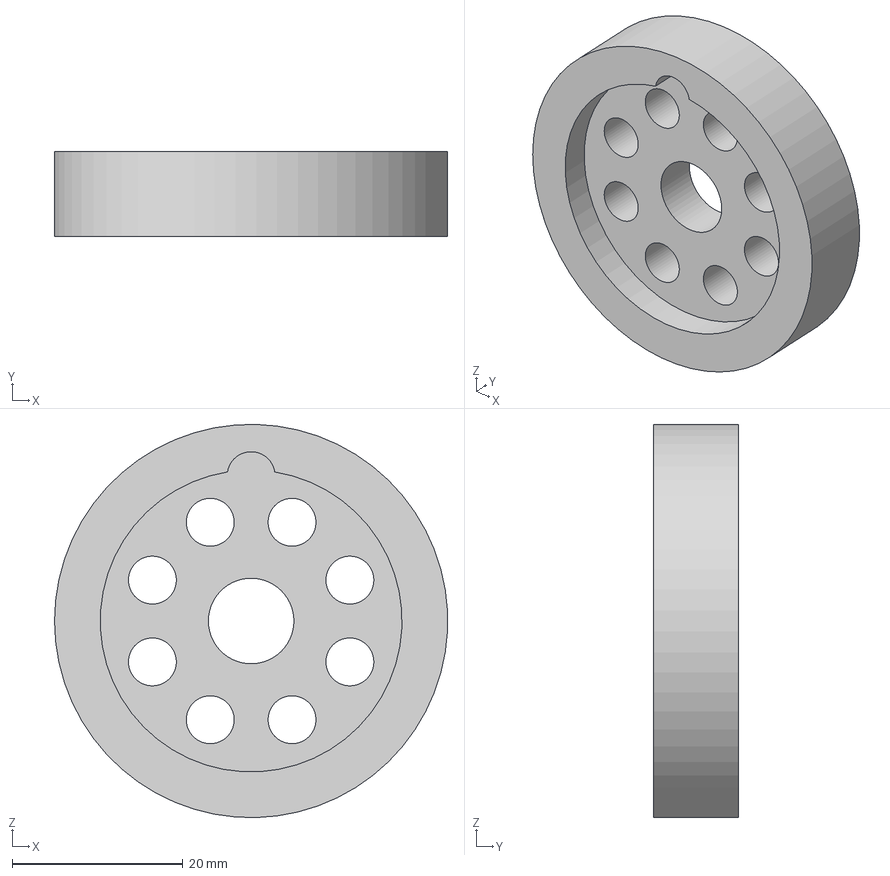
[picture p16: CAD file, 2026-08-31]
print_parts/02_j2_shoulder/009_P217_J2HubDrillJig.step
46.0 x 10.0 x 46.0 mm

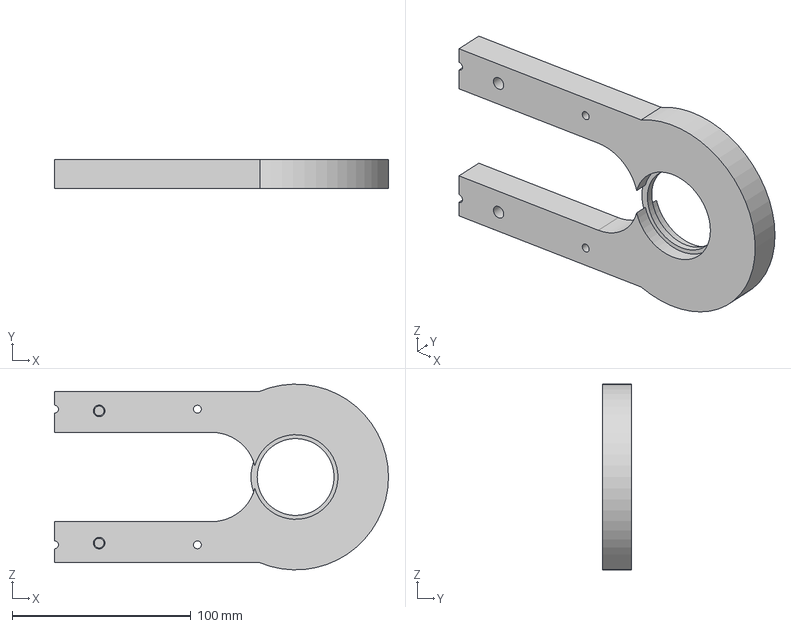
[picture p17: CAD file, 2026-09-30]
print_parts/03_j3_elbow/002_UpperArmCheek_Left_B_6807InnerShoulder.step
187.0 x 16.0 x 104.0 mm

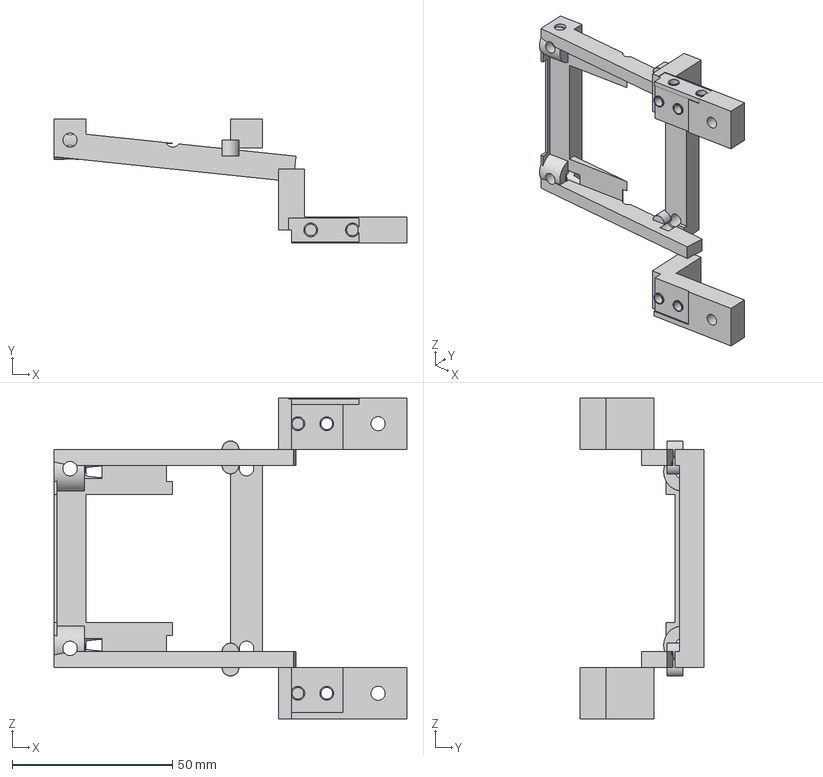
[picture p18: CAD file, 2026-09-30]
print_parts/04_j4_forearm/018_P401C_ForearmSideFrame_NegY.step
110.0 x 38.5 x 100.0 mm

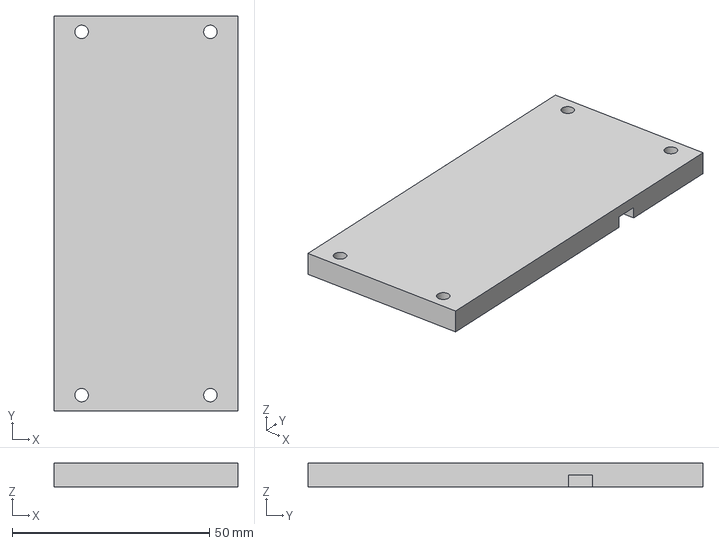
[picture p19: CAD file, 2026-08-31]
print_parts/06_gripper/009_GripperServiceCover.step
46.6 x 100.0 x 6.00 mm

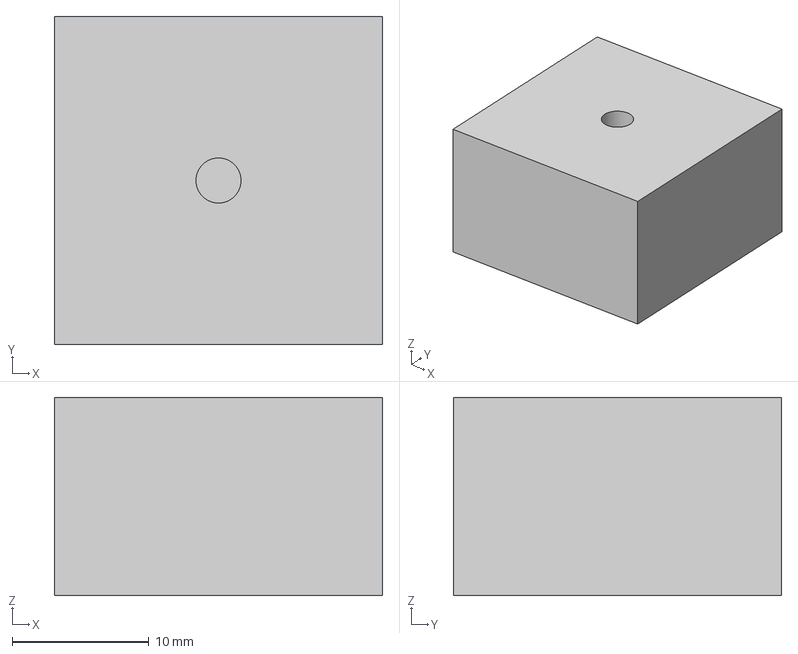
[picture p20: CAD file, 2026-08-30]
print_parts/01_base_and_j1/006_BaseFoot_MP.step
24.0 x 24.0 x 14.5 mm

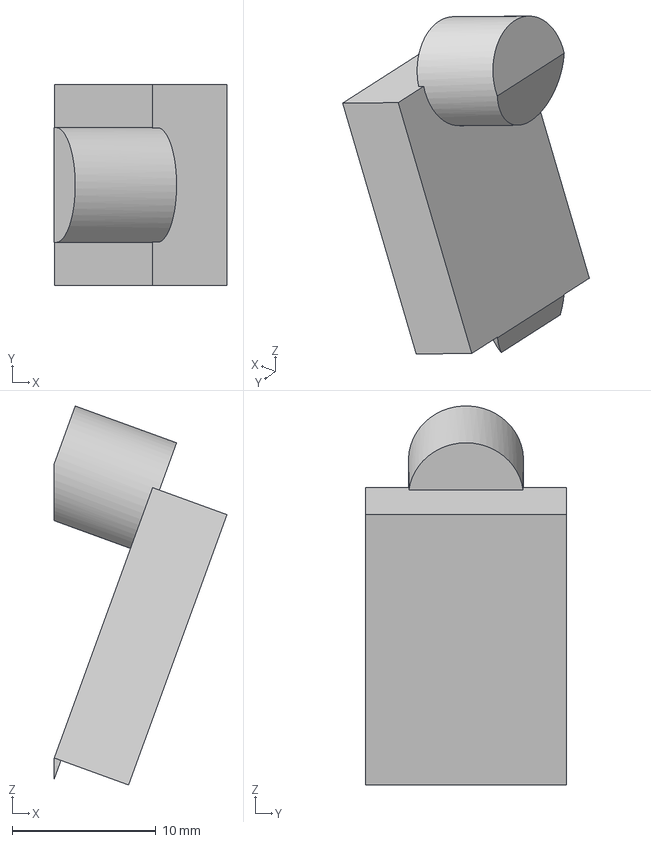
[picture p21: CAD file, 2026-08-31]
print_parts/02_j2_shoulder/001_HomeSwitchBracket_J2.step
12.0 x 14.0 x 26.4 mm

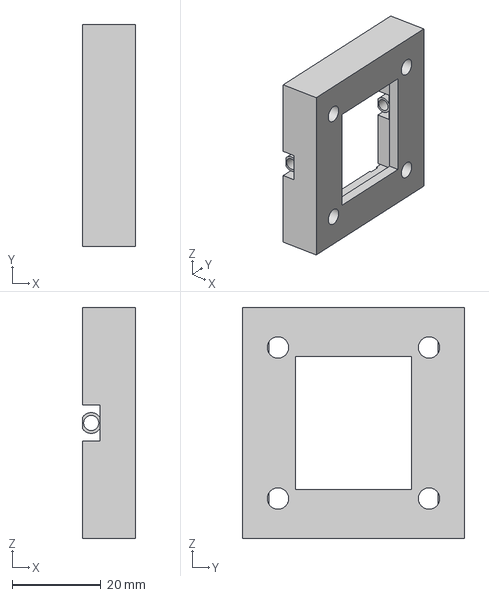
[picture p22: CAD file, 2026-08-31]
print_parts/05_j5_j6_wrist/028_OV5693_CameraGuard.step
12.0 x 50.0 x 52.0 mm

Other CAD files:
print_parts/05_j5_j6_wrist/003_DiffInputClampCollar_A.step
print_parts/07_forearm_lids/001_ForearmDorsalLid_Aligned.step
print_parts/03_j3_elbow/016_UpperArmCheek_Right_B_6807InnerShoulder_M3Pilots.step
print_parts/04_j4_forearm/005_P304E_PG19Carrier_Rear_NegY.step
print_parts/01_base_and_j1/001_BaseFloor_Left_Anchored.stl
print_parts/01_base_and_j1/002_BaseFloor_Right_Anchored.step
print_parts/01_base_and_j1/002_BaseFloor_Right_Anchored.stl
print_parts/01_base_and_j1/003_BaseFloor_UpperSplicePlate.step
print_parts/01_base_and_j1/003_BaseFloor_UpperSplicePlate.stl
print_parts/01_base_and_j1/004_BaseFloor_UpperSplicePlate_1.step
print_parts/01_base_and_j1/004_BaseFloor_UpperSplicePlate_1.stl
print_parts/01_base_and_j1/005_BaseFoot_MM.step
print_parts/01_base_and_j1/005_BaseFoot_MM.stl
print_parts/01_base_and_j1/006_BaseFoot_MP.stl
print_parts/01_base_and_j1/007_BaseFoot_PM.step
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

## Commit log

2026-08-14 First public version, printable parts
    [001_BaseFloor_Left_Anchored.step, 001_BaseFloor_Left_Anchored.stl, 001_DiffInputSpool_A.step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]
2026-08-16 Simplify assembly guide description
    Removed redundant sentence about assembly steps.
2026-08-17 First public drop: printable parts
2026-08-17 Update parts and add OV5693 camera mount
    [001_DiffInputSpool_A.step, 001_HollowInputShaft_A.step, 001_HollowInputShaft_A.stl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]
2026-08-18 Update README with AI model and camera mount details
    Added information about AI model for object detection and camera mount.
2026-08-19 Add warning about structural weaknesses, do not print it
2026-08-20 Updated part strength, removed broken edge connections
    [001_P304A_J4_BearingCartridge.step, 001_P304A_J4_BearingCartridge.stl, 002_P304B_BottomFoot_Rear.step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]
2026-08-27 Add assembly guide PDFs
2026-08-27 Updated Manuals to the current version
2026-08-29 Re-export parts, rebuild manuals
    [006_P304F_PG19Carrier_Front_PosY.step, 006_P304F_PG19Carrier_Front_PosY.stl, 007_P304G_PG19Carrier_Front_NegY.step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]
2026-08-29 Fit J4 cover to the measured motor, shorten the J3 cartridge
    [014_P216_J3_LoadCartridge_68mmGearbox.step, 014_P216_J3_LoadCartridge_68mmGearbox.stl, 022_J4_GearmotorServiceCover_Clearanced.step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]
2026-08-29 Publish assembly guide and update README content
    Updated the README to reflect the publication of the assembly guide in both Czech and English, along with details about the manuals and future plans for links to necessary items.
2026-08-29 Revise README to include assembly guide details
    Updated the README to reflect the publication of the assembly guide and added information about the manuals' contents.
2026-08-29 Enhance README with assembly guides and formatting
    Updated README to include assembly guides and formatting changes.
2026-08-30 Rework J1-J3 for the real FLF57 output, fix some bugs
    [001_BaseFloor_Left_Anchored.step, 001_BaseFloor_Left_Anchored.stl, 002_BaseFloor_Right_Anchored.step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]
2026-08-31 Fix strength issues regarding shaft connection, manuals rebuilt
    [001_ForearmDorsalLid_Aligned.step, 001_ForearmDorsalLid_Aligned.stl, 001_GripperPalm.step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]
2026-09-05 Rewrite 151 stub assembly steps, add J2 drive chapter
2026-09-05 Model wrist motors and pulleys, fix 10.3mm screw offset
2026-09-05 Cut gripper motor mount holes in P801, update manual
    [001_GripperPalm.step, 001_GripperPalm.stl]
2026-09-07 Update README with project status and design changes
    Removed outdated information about structural weaknesses and updates made to the robot arm design. Added current status of the project and clarified the focus on printable parts.
2026-09-09 Attach wrist motor mounts to forearm frame, publish missing mount parts
    [013_P401B_ForearmSideFrame_PosY.step, 013_P401B_ForearmSideFrame_PosY.stl, 018_P401C_ForearmSideFrame_NegY.step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]
2026-09-09 Add front tie to wrist motor mounts, three perpendicular joints
    [012_P401A_J4_OutputFlangeWithTabs.step, 012_P401A_J4_OutputFlangeWithTabs.stl, 013_P401B_ForearmSideFrame_PosY.step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]
2026-09-09 Add wrist mount screw steps, correct pulley fitting instruction
2026-09-30 Seat wrist motor mounts, open M4 pilot holes
    [001_UpperArmCheek_Left_A_J2SixBoltHoles.step, 001_UpperArmCheek_Left_A_J2SixBoltHoles.stl, 002_J2_FlangedBearingHub.step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]
2026-09-30 Bolt the upper arm splice plates into heat-set inserts
    [001_UpperArmCheek_Left_A_J2SixBoltHoles.step, 001_UpperArmCheek_Left_A_J2SixBoltHoles.stl, 002_UpperArmCheek_Left_B_6807InnerShoulder.step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]
2026-09-30 Add the 3D assembly guide for the browser
